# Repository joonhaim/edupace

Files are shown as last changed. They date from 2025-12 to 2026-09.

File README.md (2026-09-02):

<p align="center">
<p align="left">
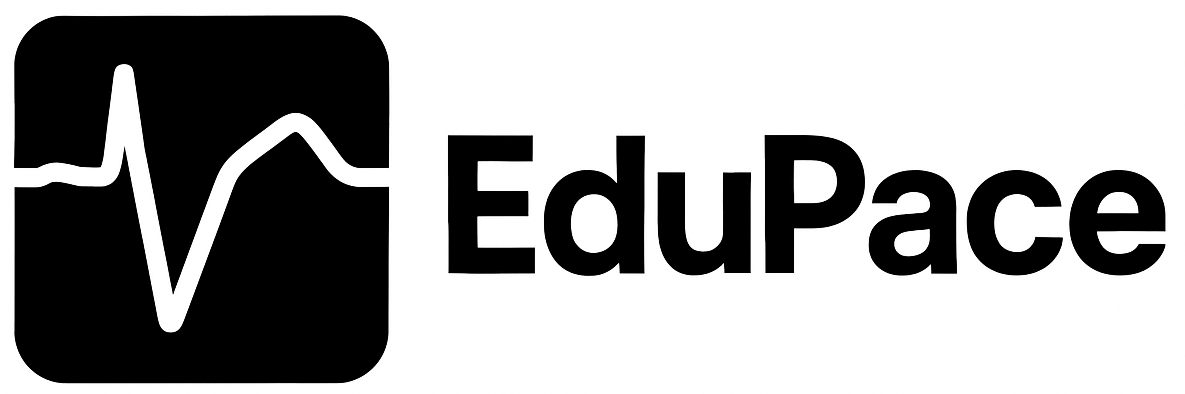
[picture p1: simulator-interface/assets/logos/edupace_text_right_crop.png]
EduPace
  
</p>
</p>

EduPace is an educational simulator that trains nurses and students to configure a temporary external single-chamber pacemaker. It provides realistic practice in pacing, sensing, and threshold adjustments by replicating the behaviour of the Medtronic 53401 Temporary External Pacemaker. The system combines a software-based ECG and pacing simulator with a physical control unit that includes knobs, LEDs, and a display, allowing users to interact with the device as they would in a clinical setting.

Developed within the TU Delft Minor Biomedical Engineering in collaboration with the Reinier de Graaf Hospital (Delft, Netherlands).

[**EduPace Project Report**](report.pdf) 

---

## Installation & Setup
[**EduPace User Manual**](simulator-interface/assets/pdf/EduPace_User_Manual_EN.pdf)

### **Web simulator**
[**Launch the EduPace simulator**](https://joonhaim.github.io/edupace/)

The hosted simulator runs in desktop Google Chrome or Microsoft Edge. Connecting the physical EduPace device requires granting USB serial access when prompted; virtual controls remain available without hardware. Session logs and optional operator names stay in the browser's local storage and are not uploaded.

### **Requirements**
- Arduino GIGA R1 WiFi
- Arduino GIGA Display Shield
- Google Chrome / Edge (WebSerial support)
- USB-C cable

### **Setup**
1. Clone this repository  
2. Upload `hardware/EduPace2025.ino` to the GIGA  
3. Open the EduPace UI in your browser or download the installer from Releases.
4. Connect the EduPace device to the computer with a USB cable.  
5. Begin a training scenario

---
## Repository Structure

```text
.
├── .github/                  # GitHub workflows and configuration
├── README.md
├── package.json               # Electron wrapper metadata and scripts
├── package-lock.json
├── cad/                       # Mechanical CAD design files and exports
├── arduino/                   # Firmware and hardware assets
│   ├── README.md
│   ├── digital.c
│   └── EduPace_final/         # LVGL UI, serial logic, and encoder handling
│       ├── *.ino
│       ├── key.c
│       ├── lv_conf.h
│       ├── edupace_logo*.{c,png}
│       └── tu_logo.{c,jpg}
├── electron/                  # Electron wrapper for the simulator
│   ├── about.html
│   ├── icons/
│   ├── main.js
│   └── preload.js
└── simulator-interface/       # ECG simulator & WebApp Interface
    ├── assets/
    ├── data/
    ├── ecg/
    ├── js/
    ├── styles/
    └── index.html
```

___

## Contributors

**Minor BME 2025 Team:** 
Ashley Jacobi, Süheyla Nurlu, Cees Vlasman, Adrien Joon-Ha Im

**Clinical Supervisor:** 
Paul Verschuren, Reinier de Graaf Hospital

---

### Contributions

**Ashley Jacobi**
- Researched physiological ECG morphology and clinical requirements
- Designed ECG generation engine (real-time Bézier-based cycles)
- Developed pacemaker timing system (sensing, inhibition, capture logic)
- Led documentation work and coordinated communication with the hospital and clinical supervisors

**Süheyla Nurlu**
- Implemented Arduino-side functionality (encoders, knobs, buttons, LEDs)
- Developed hardware interaction logic and Serial communication routines
- Managed wiring, pin mapping, and microcontroller integration

**Cees Vlasman**
- Designed enclosure components and mechanical layout (CAD modeling)
- Executed 3D printing, hardware assembly, and fit verification
- Ensured ergonomic alignment of knobs, display, and casing
  
**Adrien Joon-Ha Im**
- Designed and implemented the UI/UX flow, layout system, and visual interface
- Integrated UI components: pacing/sensing indicators, alarms, waveform rendering
- Built WebSerial communication protocol between Arduino and simulator
- Implemented PVC/PAC logic, QRS width modulation, and threshold drift
- Structured the scenario engine and front-end simulator architecture

---
## Limitations & Future Work

- Dual-chamber pacing implementation
- Improvement of morphology
- Expand number of clinical cases

---
## AI Assistance

Generative AI tools, including Codex, were used for selected non-critical development tasks. All important design choices, simulator behaviour, and final validation remained the responsibility of the project team.

---
## Disclaimer

EduPace is **for educational use only** and **not a medical device**.

---

## License
MIT License

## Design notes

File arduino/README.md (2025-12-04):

# EduPace Hardware 

## Hardware Requirements 
 - Arduino Giga R1
 - Giga Display Shield (480×800)
 - 3 Incremental Rotary Encoders (for Pace, Output, and Sense)

## Software Requirements

- Arduino IDE 
- LVGL graphics library (9.4.0)
- Arduino_H7_Video library
- Arduino_GigaDisplayTouch library
- Download digital.c file and add it inside the font folder of Arduino "C:\..\..\..\Arduino\libraries\lvgl\src\font\digital.c"

## Features

- Touch-enabled lock button
- Touch-enabled power button
- Real-time display of Pace, Output, and Sense parameters
- Rotary encoder input for adjusting values
- LED indicators for status feedback
- Serial communication for external monitoring/control
- Graphical dials and digital readouts for parameter visualization
- Flickering LED effect to simulate device activity

## Serial Communication
- Setial Baud rate: 115200
### Communication Format
► Incoming Serial Commands:
- GREEN_ON
- GREEN_OFF
- BLUE_ON
- BLUE_OFF
  
► Outgoing Serial Messages:
- PACE=< value >, OUTPUT=< value >, SENSE=< value >
- POWER_ON
- POWER_OFF

### User Interaction
► Power Button:
   - Hold > 2 seconds  → Toggle ON → OFF
   - Single press      → Toggle OFF → ON
   - ignored when locked
     
► Key Button:
- Single press  → Lock / Unlock
- If no value (pace, output, sense) has changed for more than 60 seconds, the system automatically locks.
  
► Encoder Knobs:
- Rotate to adjust PACE, OUTPUT, or SENSE
- Rotation ignored when locked
   
## Pin Connections
| Component | Signal | Arduino Pin | Notes |
|---|---|---|---|
| ENCODER 1 | CLK (A) | 2 | Pace rotary encoder |
| ENCODER 1 | DT (B)  | 3 | Pace rotary encoder |
| ENCODER 2 | CLK (A) | 6 | Output rotary encoder |
| ENCODER 2 | DT (B)  | 7 | Output rotary encoder |
| ENCODER 3 | CLK (A) | 12 | Sense rotary encoder  |
| ENCODER 3 | DT (B)  | 13 | Sense rotary encoder  |
| Power | +5V | +5V | Supply voltage |
| Ground | GND | GND | Common ground |

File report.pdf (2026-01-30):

EduPace: A Simulator for Temporary External Pacemaker Training

# EduPace: A Simulator for Temporary External Pacemaker Training

Süheyla Nurlu (5978637), Adrien Joon-Ha Im (4999924), Cees Vlasman (5708273), Ashley Jacobi (5973503)

E-mail: snurlu@tudelft.nl, aim@tudelft.nl, cvlasman@tudelft.nl, ajacobi@tudelft.nl
Abstract

Temporary external pacemakers are used to stabilise patients with acute bradycardia and atrioventricular conduction disorders. Because these devices are rarely used in daily clinical practice, nurses have limited opportunity to develop confidence in their operation. EduPace was developed as a training simulator based on the Medtronic 53401 single-chamber temporary external pacemaker. The system replicates the device’s appearance and controls using a microcontroller-based interface with rotary encoders and a graphical display, while a desktop application simulates electrocardiogram signals and pacemaker behaviour in real time. Feedback from nursing staff indicated that EduPace provides a realistic and intuitive hands-on training experience. EduPace offers an accessible tool for temporary external pacemaker education.

Keywords: Training tool, Medtronic 53401, Single-chamber external temporary pacemaker, Ventricular pacing

### 1. Introduction

A temporary external pacemaker is a device that stimulates
heart contractions to maintain a sufficient cardiac rhythm in patients suffering from various forms of cardiac arrhythmia [1]. Unlike permanent pacemakers, temporary pacemakers are not surgically implanted and are used to transiently stabilise a patient’s cardiac rhythm. They are often used during surgical procedures, or while awaiting implantation of a permanent pacemaker, to manage slow heart rhythms (bradycardia), caused by sinoatrial (SA) node dysfunction or various levels of atrioventricular (AV) blocks [2].

Temporary external pacemakers contain a pulse generator that produces an electrical signal to stimulate heart contraction. This pulse generator is connected to the heart via heart leads. In single-chamber pacemakers, leads are placed in either the right atrium or ventricle, while in double-chamber pacemakers, leads are placed in both chambers. Ventricular pacing is of particular significance in treating bradycardia caused by AV blocks, as these conditions hinder or prevent electrical conduction between the atria and ventricles. The degree of an AV block can be classified as either first, second, or third degree, with a higher degree indicating greater severity. A first-degree AV block is characterised by slow conduction between the atria and ventricles, represented by a long PR interval on an electrocardiogram (ECG) [3]. Second-degree AV blocks result in occasional loss of conduction. This appears on an ECG as a P wave not followed by a QRS complex [4]. In third-degree, or complete AV blocks, there is no conduction between the atria and ventricles, resulting in uncoordinated P waves and QRS complexes. While the intervals between adjacent P waves and adjacent R wavesremain constant, the PR interval varies, and P waves occur more frequently than R waves. Thus, this condition is characterised by a lower ventricular rate than atrial rate [5]. Left untreated, AV blocks can cause fainting, shortness of breath and reduced blood flow to the rest of the body [6].

Medtronic is a key player in the market for single-chamber temporary pacemakers, with models such as the 53401, as pictured in Figure 1, popular in hospitals worldwide [7].

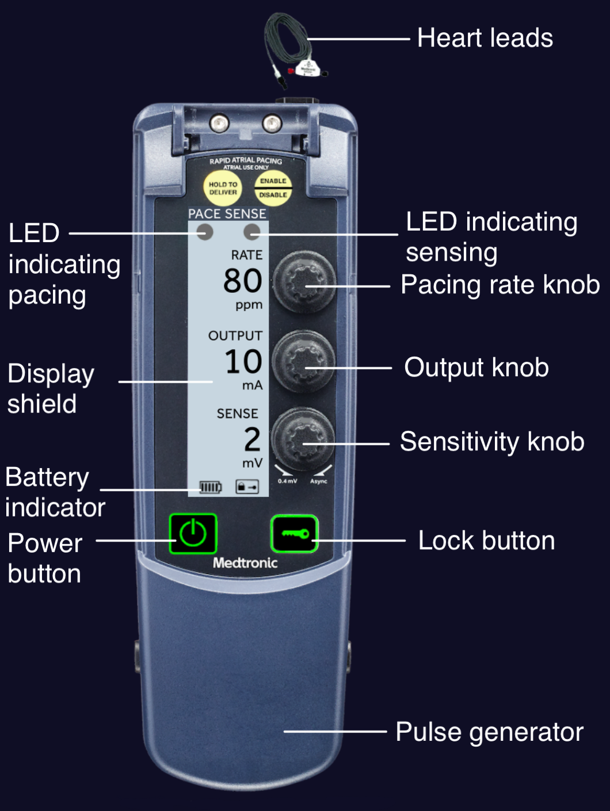
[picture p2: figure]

Figure 1: Components of Single Chamber Temporary External Pacemaker (Medtronic 53401) [8]

The pacemaker senses the patient’s intrinsic heart rhythm and paces according to the rate, output and sensitivity settings, which can be controlled using knobs on the device.

### 1.1 Problem Statement

At the Reinier de Graaf hospital, temporary external pacemakers are rarely used in the Cardiac Care Unit. Accordingly, nurses have limited opportunity to maintain routine proficiency and lack confidence in using them during emergency situations. Existing solutions to this problem include Medtronic’s VirtualEPG [8] simulation, but as this tool does not provide hands-on experience with using the device, it does not fully resolve the issue. Accordingly, the EduPace aims to address the shortcomings of the Medtronic VirtualEPG, to provide nurses with confidence in using temporary external pacemakers.

### 1.2 Project goal

The goal of this project is to develop an educational training tool that helps nurses gain practical experience and confidence in using a single-chamber temporary pacemaker for ventricular pacing. This project builds on a previous student project that successfully took the first steps toward creating a training tool for external pacing.
In the previous project, a physical training device was developed using an Arduino Mega microcontroller connected to a laptop running an ECG simulation. The system responded in real time to changes in the pacemaker settings, allowing users to see the effects of their adjustments. The final prototype of this project served as an important inspiration for the current work.
Based on feedback from hospital staff, several aspects were identified for further improvement. These include the choice of microcontroller and display shield, the overall ease of use, the realism of the simulation, and the ergonomics and appearance of the device. The aim of this project is to improve the initial design by addressing these points and by actively incorporating feedback from nurses and clinical staff throughout the development process. In this way, the final training tool is intended to better match real clinical practice and user needs.

### 2. Materials and Design

The material selection and overall design of EduPace were carefully considered to provide clinicians with an experience that closely resembles the Medtronic 53401. To achieve this, the design approach was divided in three main aspects.

The first aspect is hardware design, which focusses on the physical electronic components, including rotary encoders, the interactive display and their integration and interaction within the system. The second aspect is software design, which involves simulating ECG patterns of an imaginary patient across various clinical scenarios to support realistic training and evaluation. The third aspect is the physical device design which addresses the casing of the electronic components with emphasis on ergonomics, simplicity and ease of use.

While the hardware and physical device aim to replicate the functionality, appearance and user interaction of the Medtronic 53401 as closely as possible, the software design focusses on realistically simulating the effects of an external pacemaker on a patient.

### 2.1 Hardware Design

The hardware of EduPace is designed around the Arduino Giga R1 microcontroller along with its compatible display shield. Three incremental digital rotary encoders are integrated to adjust the rate, output and sensitivity parameters.

### 2.1.1 Microcontroller

A microcontroller is a computer on a single chip. It includes a processor (CPU), memory (RAM/ROM) and input/output (I/O) peripherals designed to perform specific tasks. Arduino is one of the most widely used microcontroller platforms which comes with its own integrated software (IDE). One of the main advantages of Arduino is its simplified programming language based on C/C++ along with a large collection of libraries, as it is an open-source platform. Further, Arduino supports a wide range of electronic components such as display shields.

Among the different Arduino boards available, the Arduino Giga R1 has been selected instead of the Arduino Mega, which was used in the previous version of EduPace. The primary reason for this choice is that the Arduino Giga R1 display shield is only compatible with the Arduino Giga R1 board. Furthermore, the display unit requires a more powerful microcontroller to run graphical libraries efficiently and provide a smooth user interface. The Arduino Giga R1 meets these requirements, as it is significantly more powerful than the Arduino Mega.

### 2.1.2 Display Shield

The display is a crucial component of EduPace, as it enables effective interaction between the device and the user. In the previous EduPace design, no graphical display was included and instead, three 7-segment displays were used to indicate current parameter values as shown in Appendix 1, Figure 1.3. However, the Medtronic 53401 includes a full display screen that shows not only the parameter values, but also labels, units, lock/unlock status of the device and LEDs for pacing and sensing activities.

To better align EduPace with the Medtronic 53401, the transition from 7-segment displays to an Arduino Giga display shield was considered an appropriate design choice, as it improves user interaction and provides greater freedom in design. The Arduino Giga display shield features an 800x480 RGB touchscreen and supports the LVGL framework, an open-source graphics library for creating user interfaces on a wide range of microcontroller and processors. Thus, the ability to use LVGL represents a significant advantage of development using Arduino.

### 2.1.3 Rotary Encoders

The Medtronic 53401 has three rotation knobs to adjust rate, output and sensitivity values. The knobs are incremental and provide a slight click at each step. Based on these design constraints, digital incremental rotary encoders were selected, as they closely resemble the behaviour and user experience of the Medtronic controls.

Each rotary encoder is powered by a 5V supply provided by the Arduino, with a common ground connection. The encoder's CLK (clock) and DT (data) pins are connected to the Arduino's digital input pins. As the knob is rotated, these two pins generate square-wave signals that are phase shifted by 90°. An algorithm created on the Arduino continuously compares the states of the CLK and DT signals to determine the direction of rotation. A difference between the DT and CLK states indicates clockwise rotation while matching states indicate counterclockwise rotation.

### 2.1.4 Layout and Graphics

When designing the layout and graphics of EduPace, similarity in design to the Medtronic 53401 and user friendliness were key considerations. EduPace starts with a splash screen (Appendix 2), so the user can click on START when they are ready to practice. Once activated, the main interface is displayed.

As shown in Figure 2, the main screen displays three indicators: Rate, Output and Sense. Each of these parameters is also represented numerically and visually through corresponding dials. At the top left and right of the screen, there are two LEDs displayed to indicate pacing and sensing. At the bottom left of the screen, there is a touchable power button, and on the bottom right, there is a Lock/Unlock button. Additionally, there is also a symbolic battery icon to make it more realistic.

Together, these elements reflect all visual features of the Medtronic 53401 while keeping the interface realistic and easier to use. Although the dials are not present on the Medtronic 53401, they are found on model 5392. They were intentionally added to improve clarity and usability.

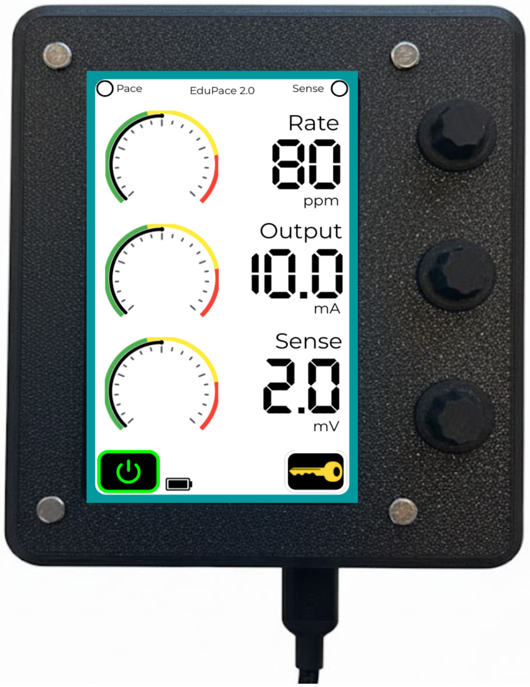
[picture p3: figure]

Figure 2: EduPace main user interface

### 2.1.5 Device Functionalities

As shown in Appendix 2, similar to the reference device, EduPace has numerous user interfaces depending on the device state. Although the EduPace device is already powered when connected to the computer, the user is still required to press and hold the power button to begin transmitting signals. To create the impression that the device is powered off, the background colour is dark grey and numerical values are replaced by two dashes. When activated, the power button turns green, default numerical values appear and the background changes to white to indicate active operation. Like Medtronic 53401, to power off the device, the power button should be pressed for more than 2 seconds, and the device must not be in the lock state.

Another key feature is the Lock/Unlock function. On the Medtronic device, locking prevents accidental changes to parameter values and the system automatically locks after 60 seconds of inactivity. EduPace follows the same principle. When the user presses the lock button, the border colour of the button turns yellow, and the background turns soft teal. Any rotation of the knobs does not affect the parameter values while locked.

Although the model 53401 has two physical LED indicators, these are simulated on the EduPace display, instead of using physical components. The left LED flashes green during pacing events, while the right LED flashes blue during sensing events. These indicators operate based on commands received from the computer.

### 2.2 Software Design and Architecture

To simulate the behaviour of the external temporary pacemaker, a desktop application was developed. The user can connect the EduPace device to the computer and launch the EduPace application following the instructions in the user manual (Appendix 11).

### 2.2.1 EduPace Desktop Application

As seen in Appendix 3, the EduPace desktop application has four main pages. The first one is the main dashboard, where the user can select the training scenario, see recent practice attempts, and track their progress. The training tab is the main page that allows the user to practice setting the correct parameters to the temporary external pacemaker. It renders the ECG waveform and responds to the rate, output, and sensitivity parameters of the connected device. After each session, the user is given feedback on whether they were successful in stabilising the patient, and how much time it took them to do so. A session log tab is also present for the user to view their previous sessions, and finally, an instructions page for quick troubleshooting.

To improve the user experience in comparison to the first iteration of EduPace, which ran as a standalone executable, the system was redesigned as a cross-platform web application using HTML, CSS, and JavaScript. This web application was then packaged as an Electron desktop app to ensure compatibility with both Windows and macOS.

The EduPace software was designed using a modular architecture to allow for future expansion. Core components such as ECG waveform generation, clinical scenario logic, and device communication were separated into independent modules. This approach allows new clinical scenarios, pacing modes, or more physiologically detailed ECG models to be added without requiring major changes to the existing system. The full EduPace application is available via a public GitHub repository (Appendix 3).

### 2.2.2 Communication Protocol

The Arduino works in conjunction with a connected computer running the EduPace software. A physical connection is made using a USB-C cable and all data exchange occurs through serial communication. The serial communication is configured to a baud rate of 115200 bits per second on both the Arduino and the computer. This rate is selected to ensure the balance between transmission speed and the communication stability. The system overview is shown in Appendix 4.

When the user adjusts the rotary encoders, the Arduino sends the updated values for rate, output and sensitivity to the computer. Furthermore, the Arduino sends a power status message whenever the device is turned on or off. These messages are received by the computer and processed by the EduPace software in real time.

The Arduino also receives control signals sent from the computer. There are four kinds of control signals that the system supports: GREEN_ON, GREEN_OFF, BLUE_ON and BLUE_OFF. When one of these signals is received, the Arduino processes the command and updates the corresponding pacing and sensing indicator LEDs on the display accordingly.

On the software side, the serial communication is handled using the WebSerial API. This allows the EduPace interface to establish connection with the Arduino without requiring additional native drivers. Compared to the previous EduPace interface, this design improves the connection stability and makes device setup simple by making it plug-and-play.

### 2.2.3 Modelling ECG Traces

ECG traces were generated using the Rational Bézier-Bernstein model coded in Python, to simulate clinically realistic cardiac patterns. This approach was inspired by a paper from Chutchavong et al. and the previous EduPace project [9]. As seen in Appendix 5, the Rational Bézier-Bernstein model takes a collection of weighted points and interpolates between these to generate a smooth trace, with additional points improving the accuracy of the interpolation. The previous EduPace project used minimal points to model ECG traces. Accordingly, to improve accuracy, it was decided to obtain additional points through importing ECG traces into the software Desmos and plotting points along the trace. As seen in Appendix 6A-E this resulted in realistic models of normal sinus rhythm, ventricular pacing and various heart conditions.

### 2.2.4 Pacemaker Logic

The functioning of pacemakers is dictated by the sensitivity, rate and output settings. Pacemakers sense a patient’s intrinsic cardiac rhythm based on sensitivity. Sensitivity describes the voltage threshold above which signals can be detected. Thus, a lower value indicates that more signals will be detected, and the pacemaker is said to have a high sensitivity. If the signal detected by the pacemaker falls below the set rate, the pacemaker will decide to pace. Pacemakers have an additional setting referred to as “Async”, where sensing does not occur and the pacemaker paces at the set rate, regardless of the patient’s intrinsic cardiac rhythm. Pacing will result in cardiac depolarisation and thus, a heartbeat, if the output current is sufficient. The output threshold above which pacing results in cardiac depolarisation is referred to as the capture threshold.

To understand how to model the behaviour of the pacemaker, a decision tree was created, as seen in Appendix
7. This logic was then transferred to functions in Python that generate an ECG waveform that illustrates how the pacemaker responds to the input simulated patient heart rhythm and pacemaker settings.

### 2.3 Physical Device Design

The physical device is designed by focusing on the casing, with particular attention to ergonomics, simplicity, and ease of use. The goal was to create a device that closely resembles the look and feel of the original Medtronic 53401, making it familiar to clinicians and easy to use in practice.

Special attention was given to the dimensions, material, and shape of the device. To enhance usability, the casing was designed to be as thin and lightweight as possible, while still providing enough structural support. From an ergonomic perspective, the device was intended to be comfortable to hold and operate with one hand during training sessions. The final 3D CAD model can be seen below in Figure 3.

Figure 3: 3D CAD Model of EduPace Casing

### 3. Results

A survey (Appendix 8) was conducted and feedback from nurses was collected. The results (Appendix 9) indicate that EduPace is perceived as a valuable training device. Across respondents, participants indicated that repeated use would help them build or maintain confidence. EduPace received high ratings for ease of use, physical design, and overall usability, which support the suitability of the device as a training platform, especially for nurses that have limited prior exposure to external pacemakers.

However, some limitations were identified, primarily related to clinical realism and ECG behaviour for edge cases. Multiple respondents noted that certain rhythms such as second- and third-degree AV blocks were not always accurately represented. Additionally, issues related to pacing and sensing indicators during threshold adjustments were reported. These findings suggest that while EduPace performs well, further refinement of the ECG modelling and indicator logic is necessary to meet the expectations of more experienced users.

### 4. Discussion

This project builds on a previous student project that already included real-time ECG simulation and device interaction. This project focussed on three main changes. First, the hardware was updated to better resemble the controls and interface of the Medtronic 53401. Second, the ECG simulation software was adjusted to create more realistic pacing behaviour and clinical cases. Third, the device casing was redesigned to improve the ease of use. Feedback from nurses and clinical staff showed that these changes made the system easier to use and closer to clinical practice.

While the previous EduPace served as inspiration, the new iteration of the device had to be designed from scratch (see Appendix 1 for a comparison between the versions), which was very time consuming. Several challenges slowed down the development process. The 3D-printed casing had to be redesigned multiple times because early versions were too small or there were problems with the 3D printer. Rendering smooth ECG traces in real time was technically difficult, which is why the ECG display is not yet fully smooth. After feedback from clinical staff, the ECG logic had to be adjusted to better reflect pacing behaviour. A simplified ECG model was used, so some physiological signal features, such as signal superposition, are not yet included. Getting frequent feedback from hospital staff was difficult due to limited availability. The EduPace team consisted of engineering students only, which meant there was limited clinical knowledge within the team. This made it harder to fully understand the medical background of temporary pacing.

At this stage, EduPace only supports ventricular pacing modes. Atrial pacing and dual-chamber pacing are not yet included. Later versions could add these modes and include more clinical training cases. EduPace is a step towards a practical and user-focused training tool for temporary external pacemakers. With future additions in pacing modes, ECG realism, and training scenarios, the system can grow into a useful tool for pacemaker education.

Acknowledgements

We would like to thank our project supervisor Paul Verschuren and nurse Kim who have supported us through the development process. We would also like to extend our thanksto TU Delft for funding the development of this project (see Appendix 10 for associated costs).

References

[1] M. Crofoot, A. Sarwar, and A. J. Weir, “External pacemaker,” StatPearls - NCBI Bookshelf, Sep. 12, 2022.
[2] J. A. Puette, R. Malek, I. Ahmed, and M. B. Ellison, “Pacemaker insertion,” StatPearls - NCBI Bookshelf, Oct. 06, 2024.
[3] J. L. Buttner, “First degree heart block,” Life in the Fast Lane • LITFL, Jun. 11, 2024. https://litfl.com/first-degree-heart-block-ecg-library/
[4] E. B. Buttner, “AV Block: 2nd degree, Mobitz II (Hay block),” Life in the Fast Lane • LITFL, Oct. 31, 2025. https://litfl.com/av-block-2nd-degree-mobitz-ii-hay-block/
[5] J. L. Buttner, “AV block: 3rd degree (complete heart block),” Life in the Fast Lane • LITFL, Nov. 15, 2023. https://litfl.com/av-block-3rd-degree-complete-heart-block/
[6] “Heart block,” Cleveland Clinic, Oct. 14, 2025. https://my.clevelandclinic.org/health/diseases/17056-heart-block
[7] “Medtronic single-chamber temporary pacemaker.” https://www.medtronic.com/en-us/healthcare-professionals/products/cardiac-rhythm/pacing-systems/temporary-pacemakers/medtronic-single-chamber-temporary-pacemaker.htm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
[8] “VirtualEPG.”
https://epicardiowebgl.s3.amazonaws.com/mdt/epg/index.ht ml
[9] V. Chutchavong, K. Nualon, O. Sangaroon, and K. Janchitrapongvej, “A mathematical model for ECG waveform using rational Bezier curves and Bernstein polynomials,” IEEE, pp. 1–5, May 2014, doi: 10.1109/ecticon.2014.6839844.

# Appendix

Appendix 1: Medtronic 53401 vs EduPace

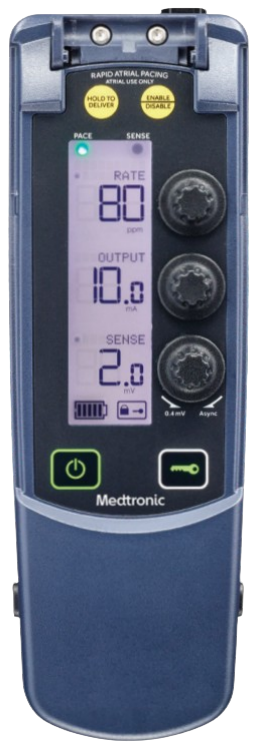
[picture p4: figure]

Figure 1.1: Medtronic 53401

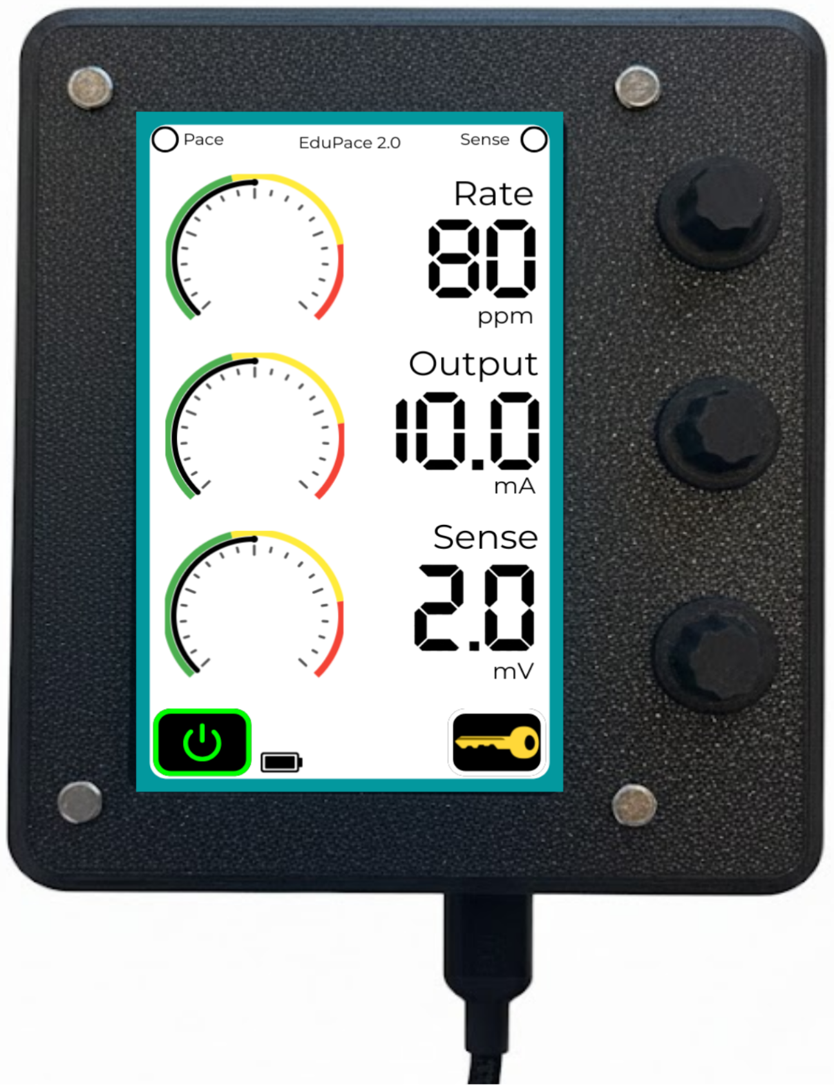
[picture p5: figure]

Figure 1.2: EduPace 2.0

Figure 1.3: EduPace 1.0

Feature | Medtronic 53401 | EduPace 1.0 | EduPace 2.0
Screen | Present | Not present | Present
Rate, output and sense indications and units | Present | Present in the form of text on stickers | Present
Rate, output and sense current values | Present | Present on 7-segment display | Present
Rate, output and sense values visual indicators | Not present, present on model 5392 | Not present | Present
Rate, output and sense rotary knobs | Present | Present, not similar to Medtronic | Present
Power button | Present | Not present | Present
Lock button | Present | Not present | Present
Pacing status indicator LED | Present | Present | Present on the display
Sensing status indicator LED | Present | Present | Present on the display
Lock indicator | Present | Not present | Not present, indicated by lock button colour change
Battery indicator | Present | Not present | Present but not functional
Asynchronous mode indication | "async" text shown, "--" instead of sense value | Present as LED | "async" text shown, "--" instead of sense value
RAP indicator LED | Present | Not present | Not present
Hand-held size | Present | Not achieved | Achieved
Protection cover | Present | Not present | Not present

Appendix 2: User Interface States

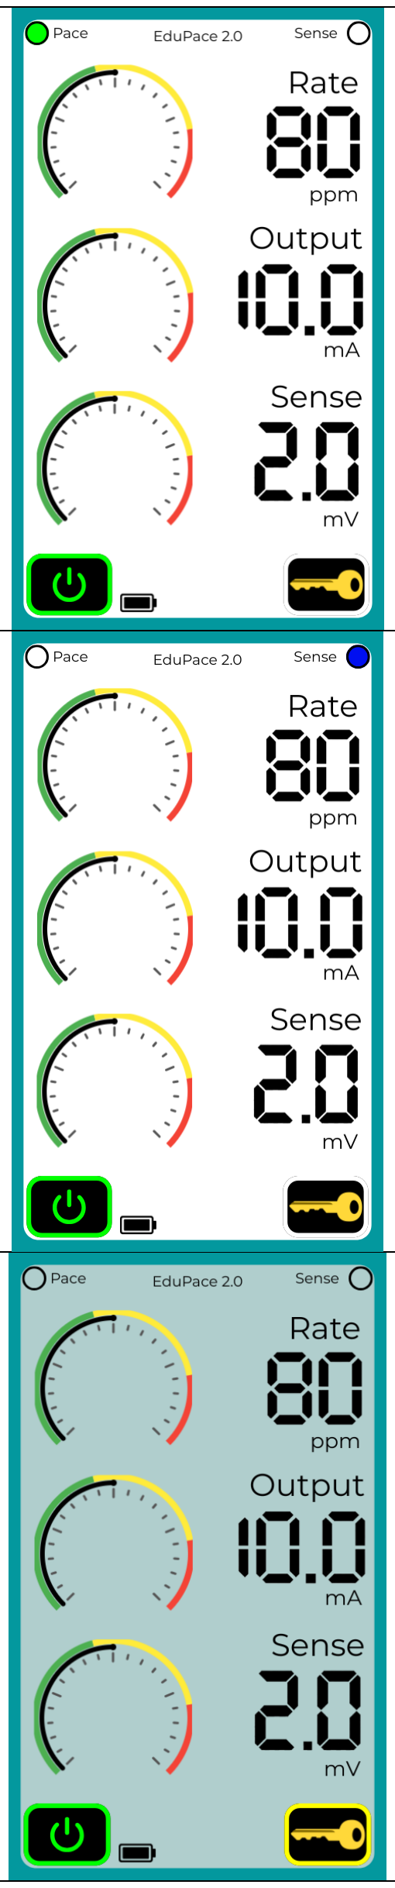
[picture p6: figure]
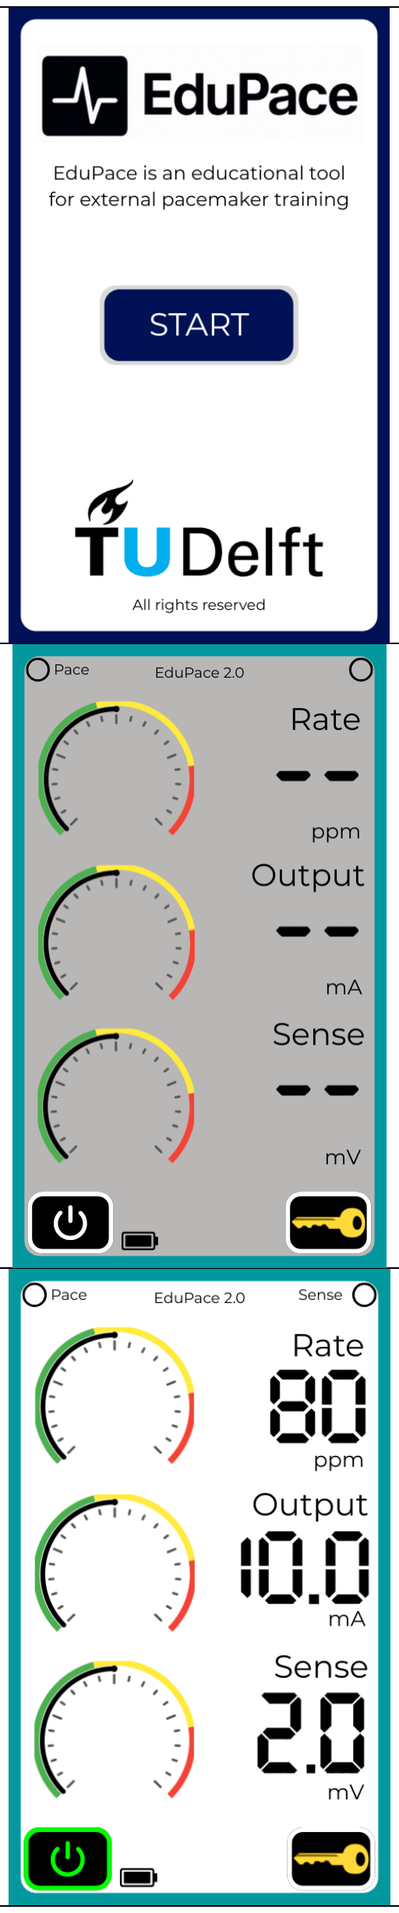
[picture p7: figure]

Splash screen Definition of EduPace and logos are shown

Power Off Background: dark grey Power button: inactive Lock button: inactive Dashes instead of numerical values

Power On Background: white Power button: active Lock button: inactive Variables start with default values

During Pacing Left LED at top is flashing green

During Sensing Right LED at top is flashing blue

System Locked Background: soft teal Lock button: active Variable values and dashes do not change

Appendix 3: EduPace App Interface

EduPace GitHub repository link: https://github.com/joonhaim/edupace A3.A Dashboard
The dashboard is the main landing screen and includes
navigation menus, a list of scenarios, progress tracking,
leaderboards, and recommendations for subsequent practice modules.

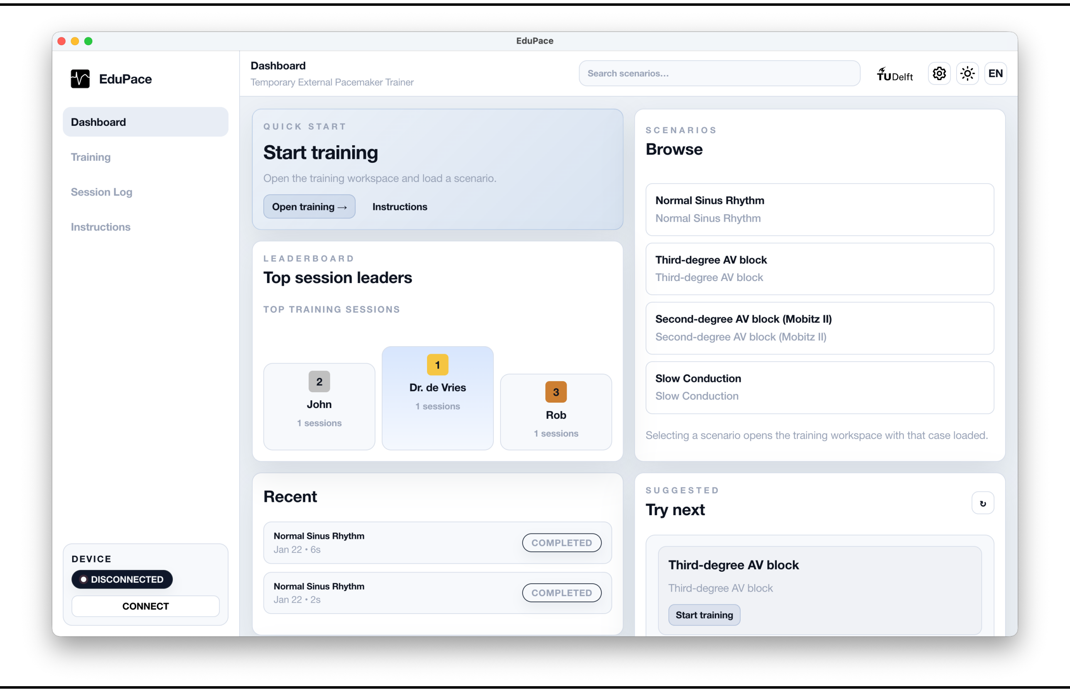
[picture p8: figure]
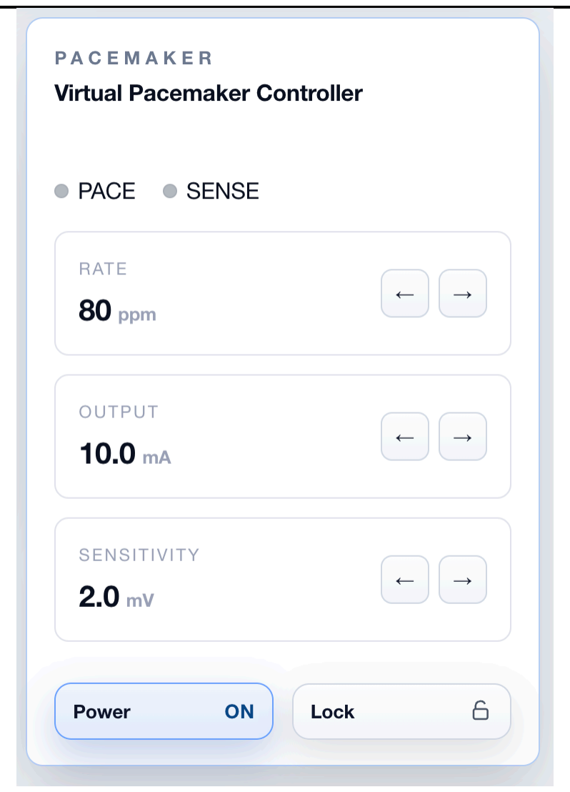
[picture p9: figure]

A3.B Training Tab
The Training tab is the main interface where ECG signals are simulated and users can adjust pacing parameters to practice appropriate pacemaker configuration.

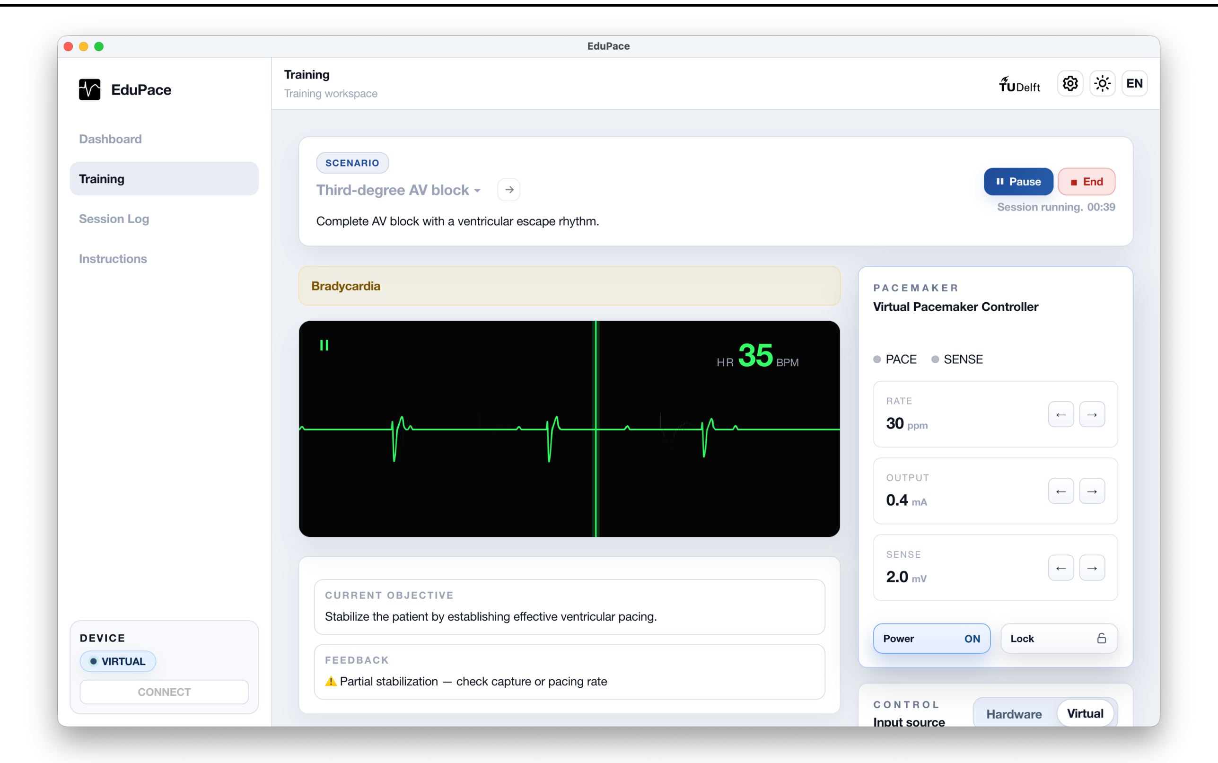
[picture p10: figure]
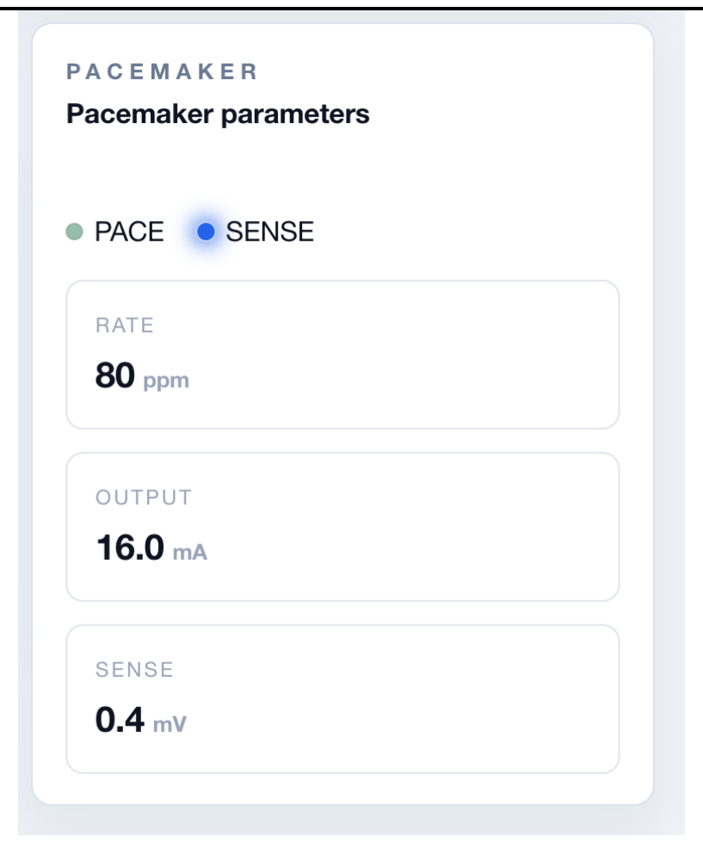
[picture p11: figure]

A3.C Session Review
After each session, a review is shown indicating whether the patient was successfully stabilized and the time required to achieve stabilization.

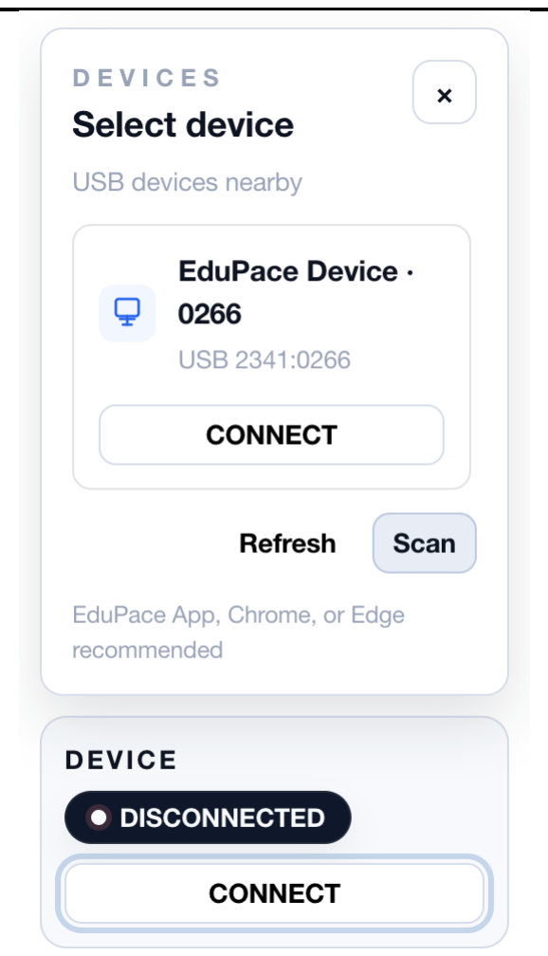
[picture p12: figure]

A3.D Connection
module

The connection module
allows users to connect
to a physical EduPace
device. Available
devices are listed and
pressing ‘CONNECT’
establishes
communication via
WebSerial.

A3.E Virtual Pacemaker The virtual pacemaker emulates the EduPace device when no hardware is connected. Pacing parameters, power and lock controls, as well as pace and sense indicators, remain fully functional.

A3.F Pacemaker Information The pacemaker information panel replicates the display of the physical EduPace device. When connected via USB, parameter values are updated using the physical control knobs.

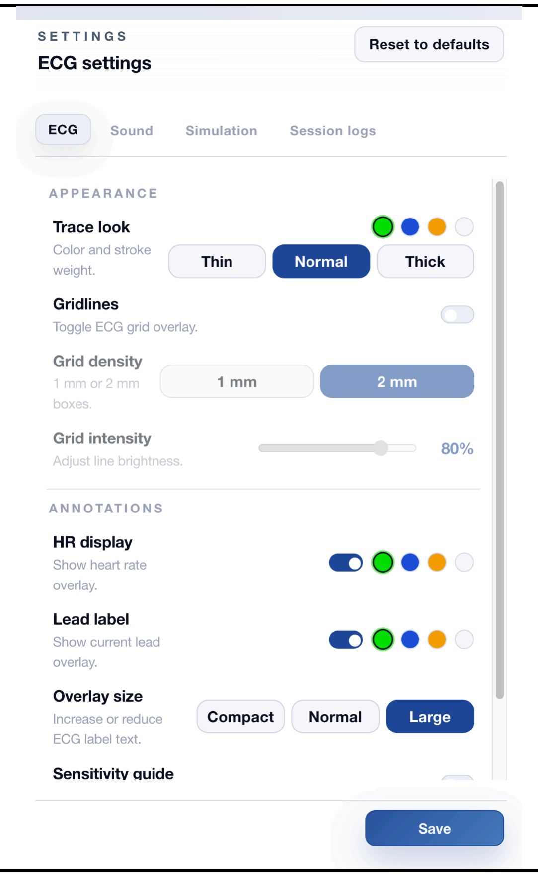
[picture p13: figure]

A3.G Settings pane The settings pane allows users to adjust application settings, including ECG appearance and overlays, as well as simulation parameters such as intrinsic heart rate.

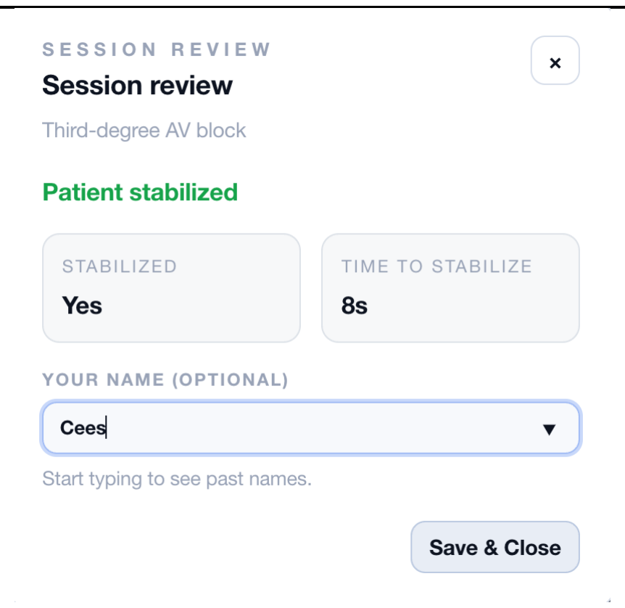
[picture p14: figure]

Appendix 4: System overview

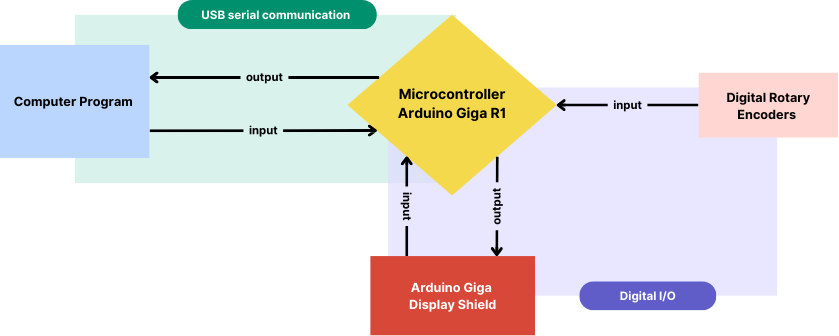
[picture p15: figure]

Appendix 5: Rational Bézier-Berstein Model

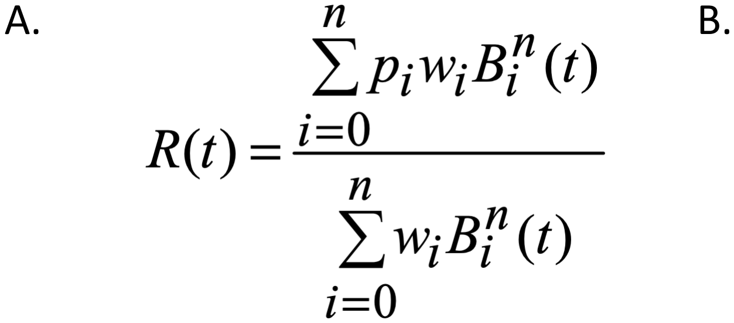
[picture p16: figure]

A5.A Trace R generated using Rational Bézier-Bernstein Model, where p is a point, w is a weighting factor and B is defined as in A5.B

Appendix 6: ECG traces

A

B

C

D

E

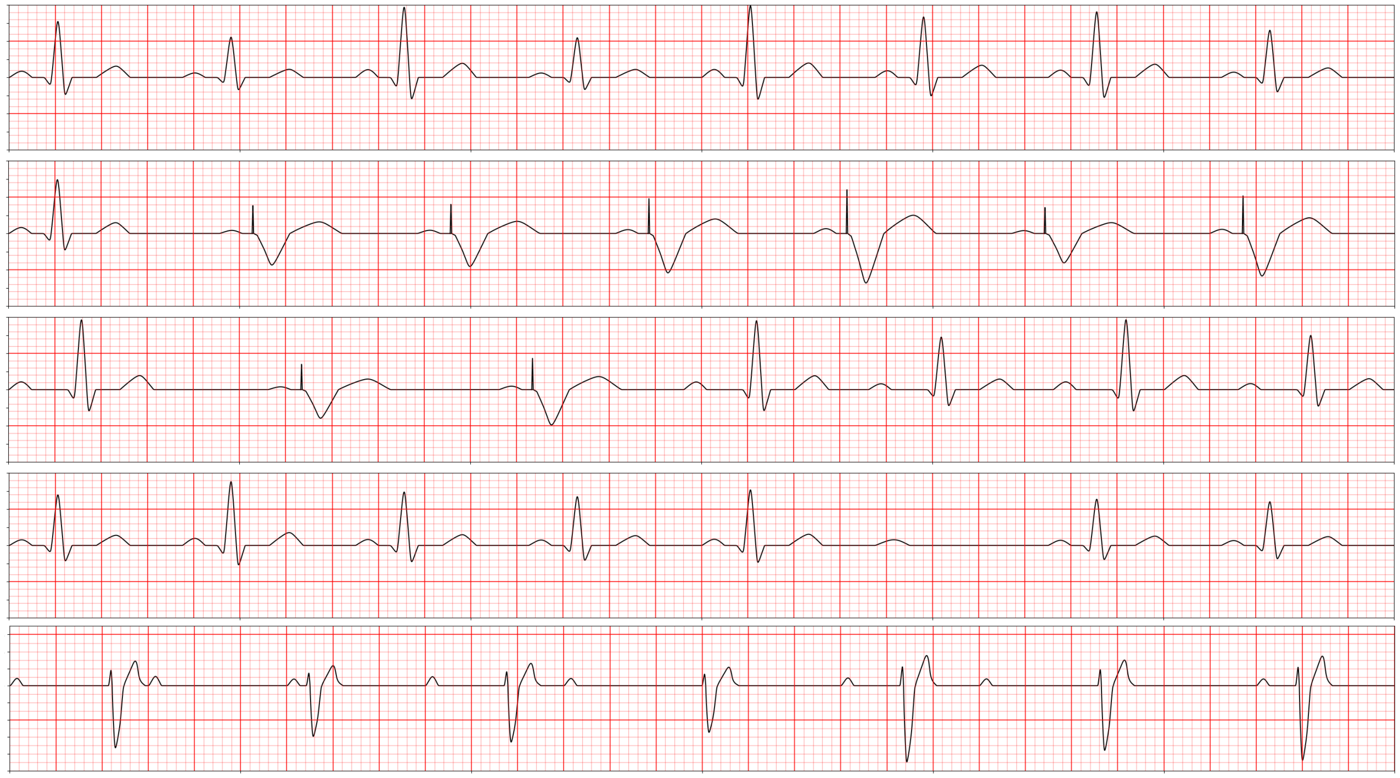
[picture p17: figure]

A6.A Normal ECG trace for patient heart rate of 80bpm A6.B Ventricular pacing for patient heart rate of 40bpm (bradycardia), pacemaker rate of 70ppm, sensitivity of 0.5mV and output of 1.7mA A6.C ECG trace for first degree heart block for patient heart rate of 75bpm, pacemaker rate of 60ppm, sensitivity of 0.7mV and output of 1.7mA A6.D ECG trace for second degree heart block for patient heart rate of 80bpm, pacemaker rate of 90ppm, sensitivity of 0.5mV and output of 1.3mA. Pacing doesn’t occur, as capture threshold isn’t reached A6.E ECG trace for third degree heart block for patient heart rate of 70bpm, pacemaker rate of 80ppm, sensitivity of 0.4mV and output of 1.3mA. Pacing doesn’t occur, as capture threshold isn’t reached

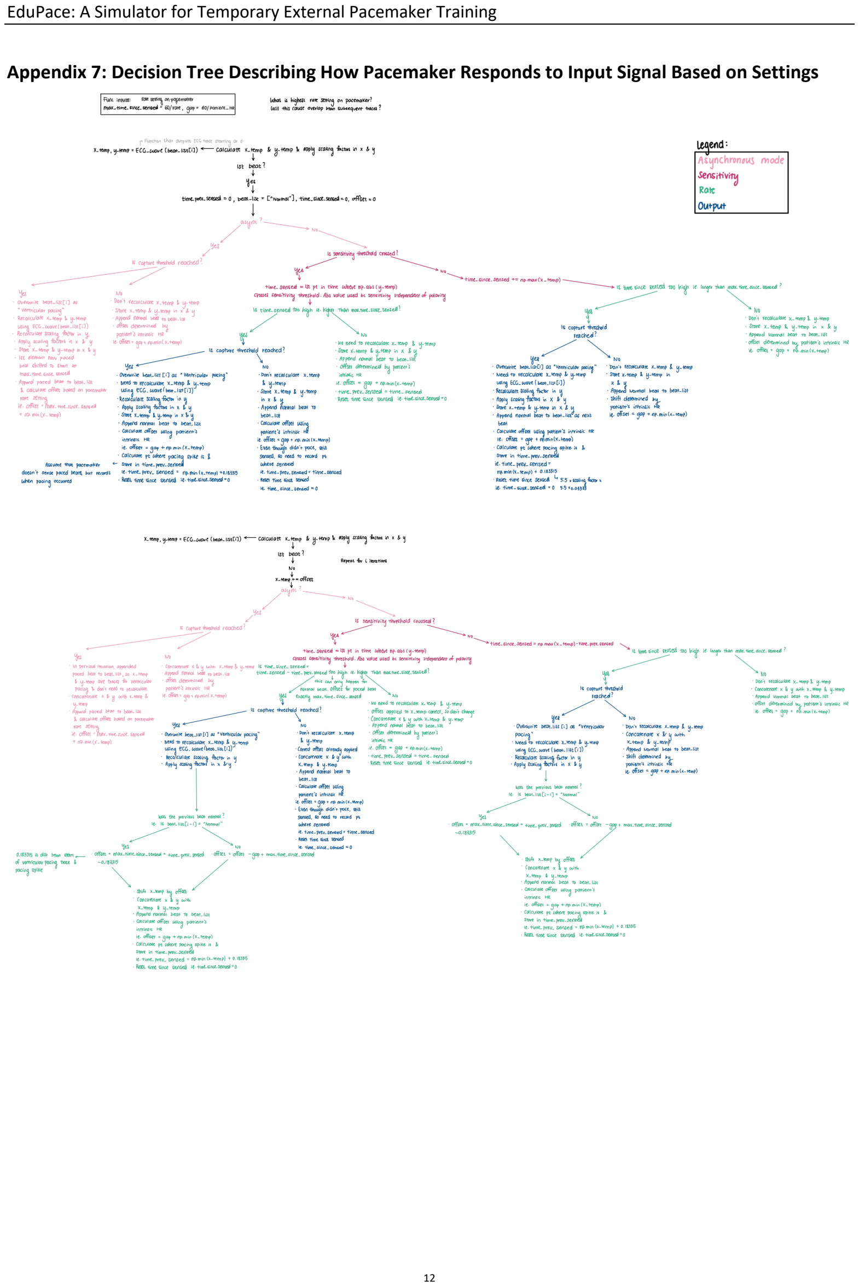
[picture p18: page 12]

Appendix 7: Decision Tree Describing How Pacemaker Responds to Input Signal Based on Settings

Appendix 8: Feedback Form

1- Role/Profession
2- Years of clinical experience
a. Less than 1 year
b. 1-3 years
c. 4-7 years
d. 8+ years

Before Using EduPace: Background
3- Have you previously used the Medtronic 53401 external pacemaker?
a. Yes
b. No
4- How long has it been since you last used the Medtronic 53401?
a. Less than 6 months
b. 6-12 months
c. More than 1 year
5- How often have you used the Medtronic 53401?
a. Rare
b. Occasionally
c. Frequently
d. Very frequently
6- Have you used any other external pacemaker?
a. Yes
b. No

Confidence & Expectations
7- How confident are you in using the Medtronic 53401 before using EduPace?
a. 1 to 10 (Not confident at all à Very confident)
8- Do you believe EduPace will help improve your pacing-related skills?
a. 1 to 5 (Not at all à Very much)
9- What specific skills would you like to practice?
a. Basic device setup
b. Understanding pacing modes
c. Adjusting output and sensitivity
d. ECG interpretation
e. Other

After Using EduPace – Self-Confidence & Learning 10- How confident do you feel after practicing with EduPace?
a. 1 to 10 (Not confident at all à Very confident)

11- Do you think practicing more often with EduPace would help build or maintain your confidence?
a. Yes
b. No
c. Unsure

12- To what extent did EduPace help you practice the skills you wanted?
a. 1 to 10 (Not at all à Completely

Product Experience
13- Did EduPace meet your expectations?
a. Not at all
b. Partially
c. Mostly
d. Completely
14- Which features did you find most useful?
a. EduPace device
b. EduPace software
c. Device layout and controls
d. Realistic ECG simulation
e. Pacing modes
f. User guide
15- How realistic did the training feel compared to a real external pacemaker?
a. 1 to 5 (Not realistic à Very realistic)
16- How easy was it to navigate on EduPace software?
a. 1 to 5 (Very difficult à Very easy)
17- How satisfied are you with the physical design and appearance of EduPace?
a. 1 to 5 (Very dissatisfied à Very satisfied) 18- How would you rate the overall ease of use of EduPace?
a. 1 to 5 (Very difficult à Very easy)
19- How clear was the user manual?
a. 1 to 5 (Not clear at all à Very clear)

Overall Feedback
20- What suggestions do you have for improving EduPace? Which aspects of EduPace do you think work well and should remain unchanged?
21- Would you recommend EduPace as a training tool to others?
a. Yes
b. No
c. Maybe
22- Anything else you would like to share about your experience with EduPace?

Appendix 9: Results From Feedback Form

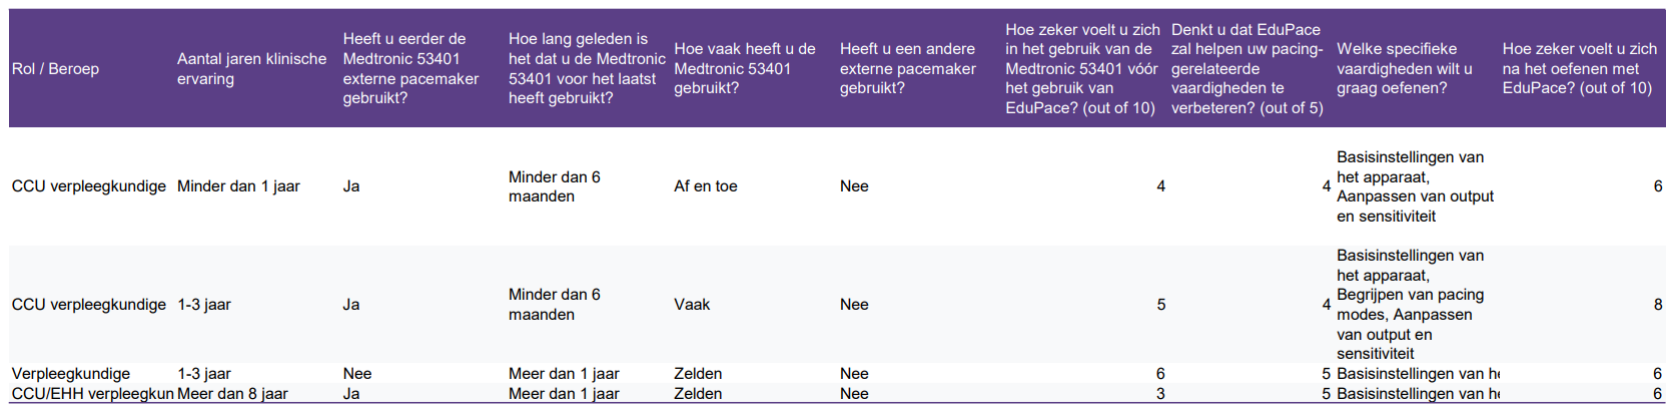
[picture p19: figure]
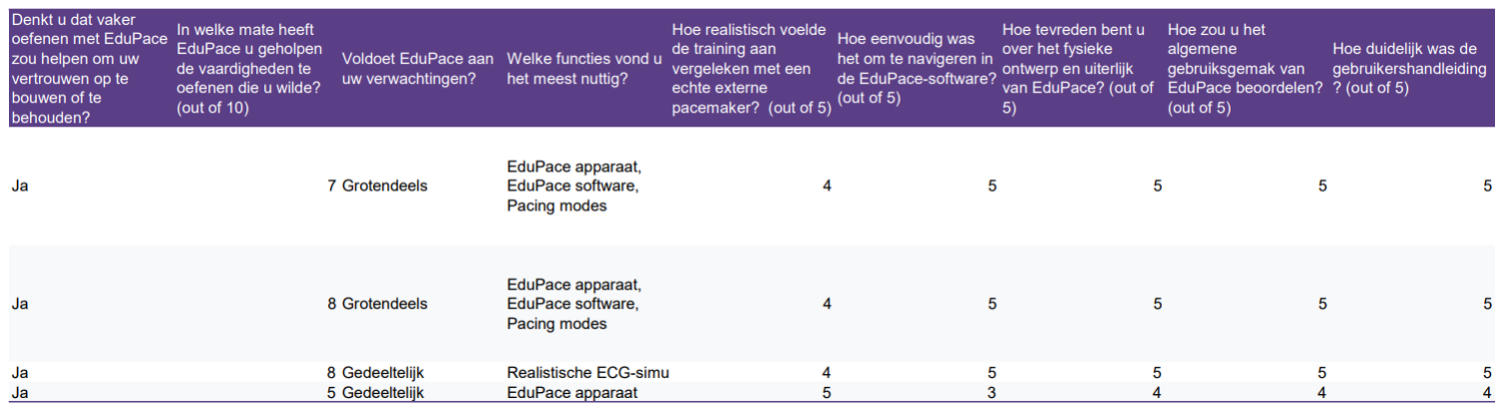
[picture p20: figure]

Appendix 10: Bill of Materials

| Qty | Unit Price (€) | Total (€)
Arduino Giga display bundle | 1 | 96.65 | 96.65
Rotary Encoders | 4 | 2.40 | 9.60
Jumper cables | 1 | 1.70 | 1.70
USB C to A cable | 1 | 2.49 | 2.49
Logo stickers | 1 | 2.25 | 2.25
Shipping cost | | | 4.99
Shipping cost | | | 6.87
Total | | | € 124.55

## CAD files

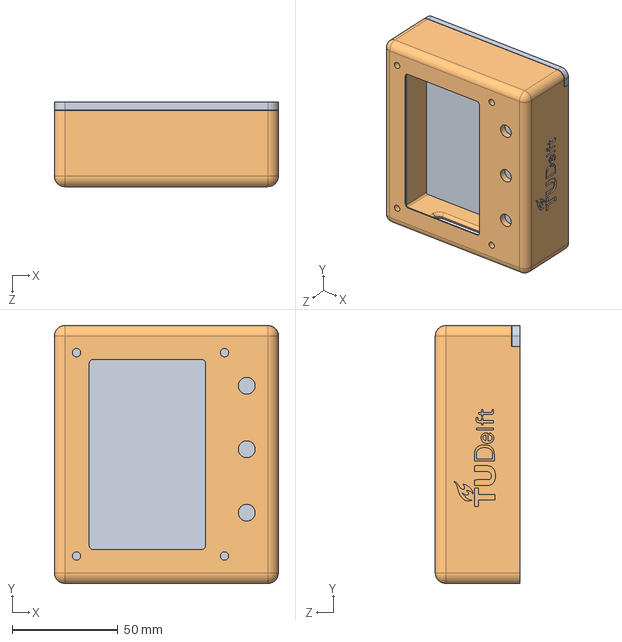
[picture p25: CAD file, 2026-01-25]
cad/Assembly EduPace.SLDASM
106.1 x 122.0 x 40.0 mm
Enclosure EduPace
Backside EduPace

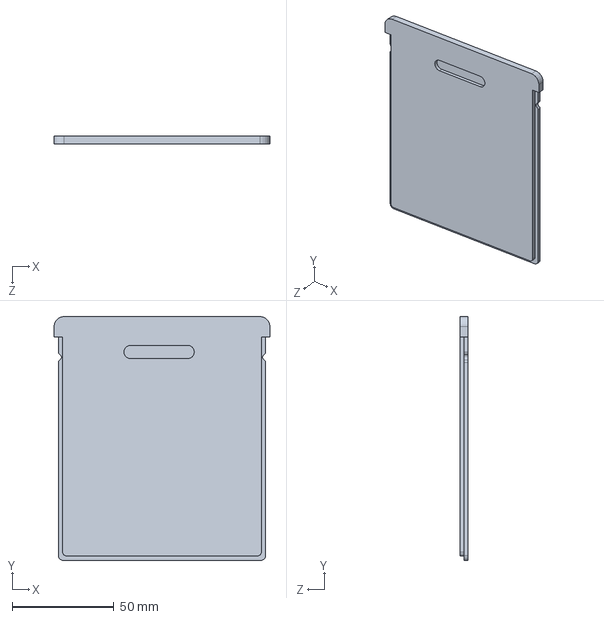
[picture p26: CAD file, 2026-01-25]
cad/Backside EduPace.SLDPRT
106.0 x 119.8 x 3.80 mm

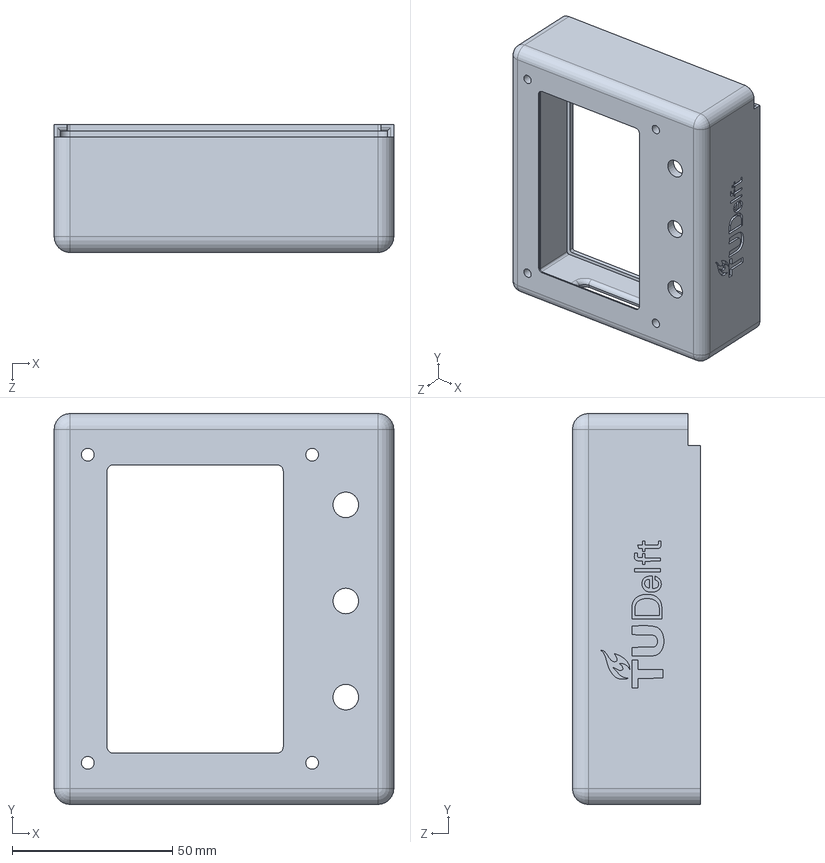
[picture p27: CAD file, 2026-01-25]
cad/Enclosure EduPace.SLDPRT
106.0 x 122.0 x 40.0 mm

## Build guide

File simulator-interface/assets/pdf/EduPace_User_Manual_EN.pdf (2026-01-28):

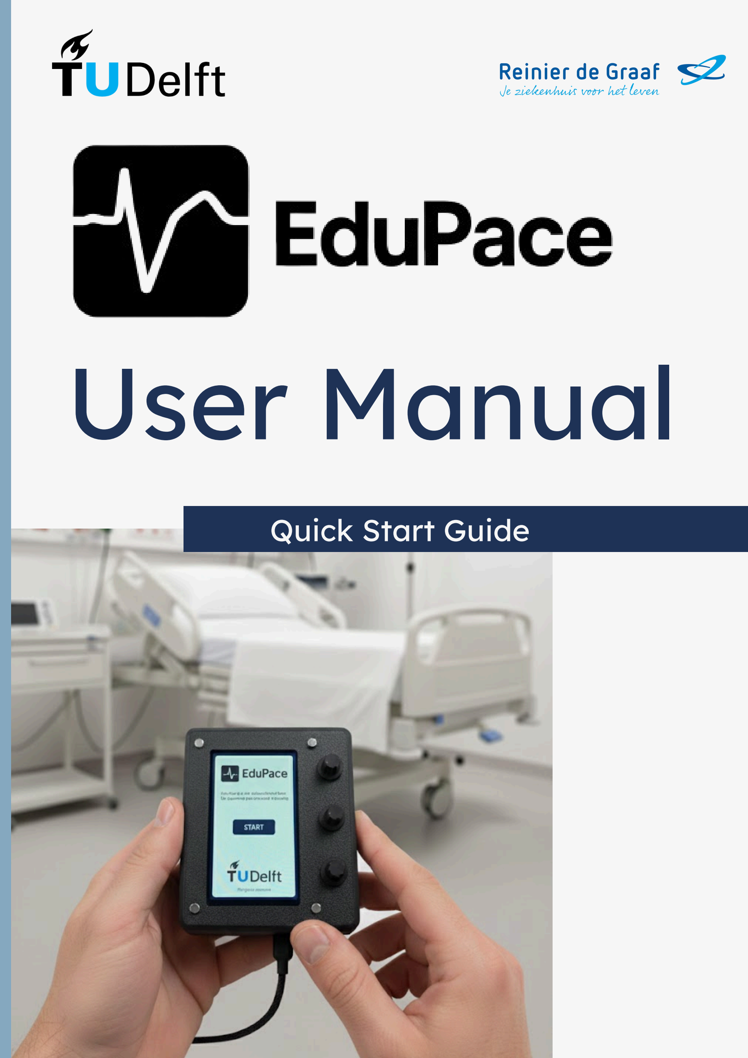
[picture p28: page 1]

# User Manual

## Quick Start Guide

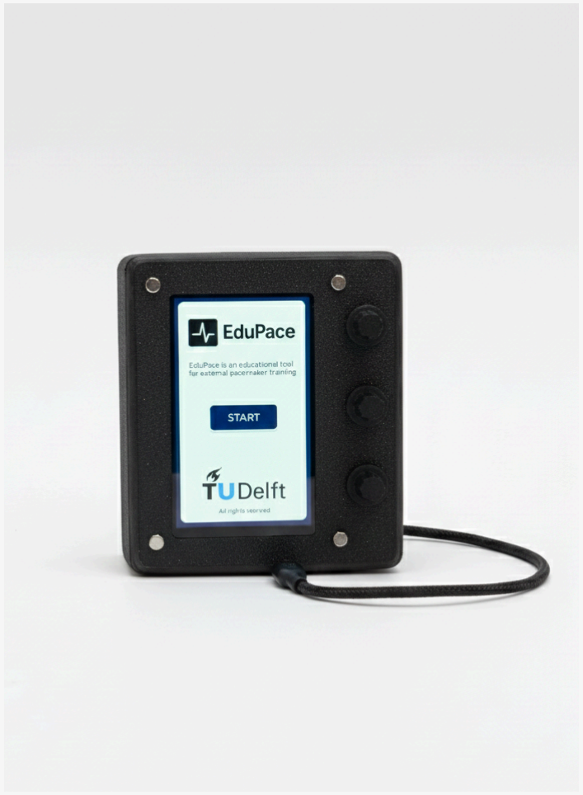
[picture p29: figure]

All rights reserved 2025

# What is EduPace?

EduPace is an educational training tool designed for practicing the use of an external pacemaker. It has been developed by university students from TU Delft for educational purposes, specifically to support the training of nurses and clinicians.

## Before you begin

# Reference Device

The design and functionality of EduPace are based on the Medtronic 53401 External Pacemaker, which was used as a reference during development.

# Disclaimer

EduPace is not a medical device and is not intended for clinical use. It is an educational exercise tool only and must not be used for diagnosis, treatment, or patient care. Always use certified medical devices in clinical settings.

## Controls and Indicators

8 | 9 | 10

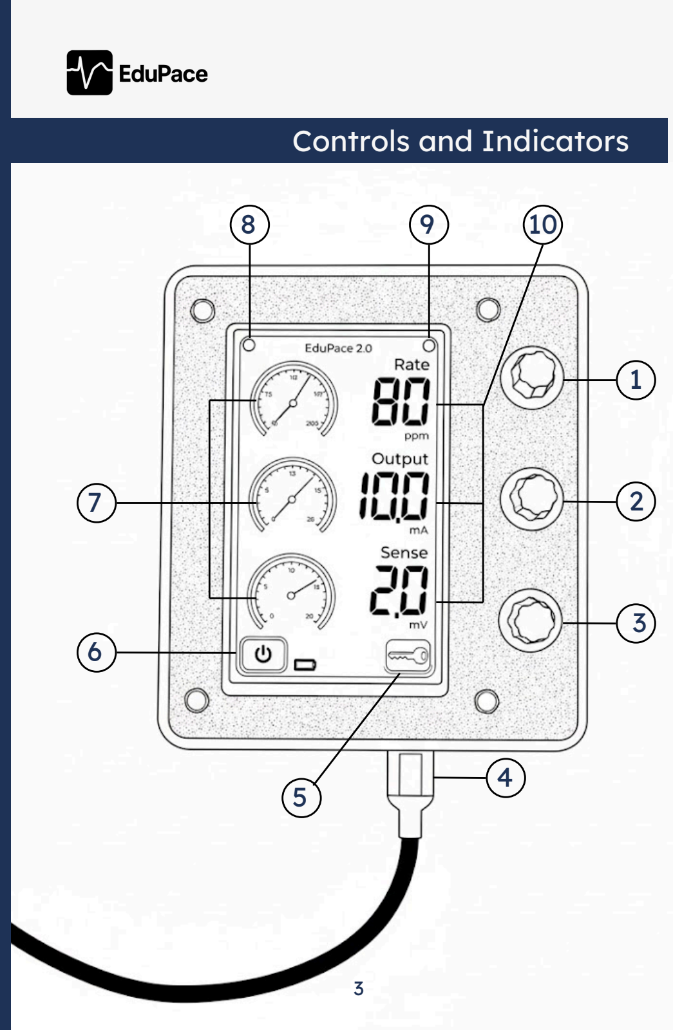
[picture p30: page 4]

1

2

3

4

6

5

7

## Controls and Indicators

### 1. RATE dial 2. OUTPUT dial 3. SENSE dial 4. USB-C input 5. Touchable Lock/Unlock button 6. Touchable On/Off button 7. Dashboard for RATE, OUTPUT, SENSE 8. Pacing status indicator LED 9. Sensing status indicator LED 10. Numeric indicators for RATE, OUTPUT, SENSE

## System Installation

# Software Installation

1.Open a web browser and go to https://github.com/joonhaim/edupace.git

2.Click on Releases on the right side of the page as shown below.

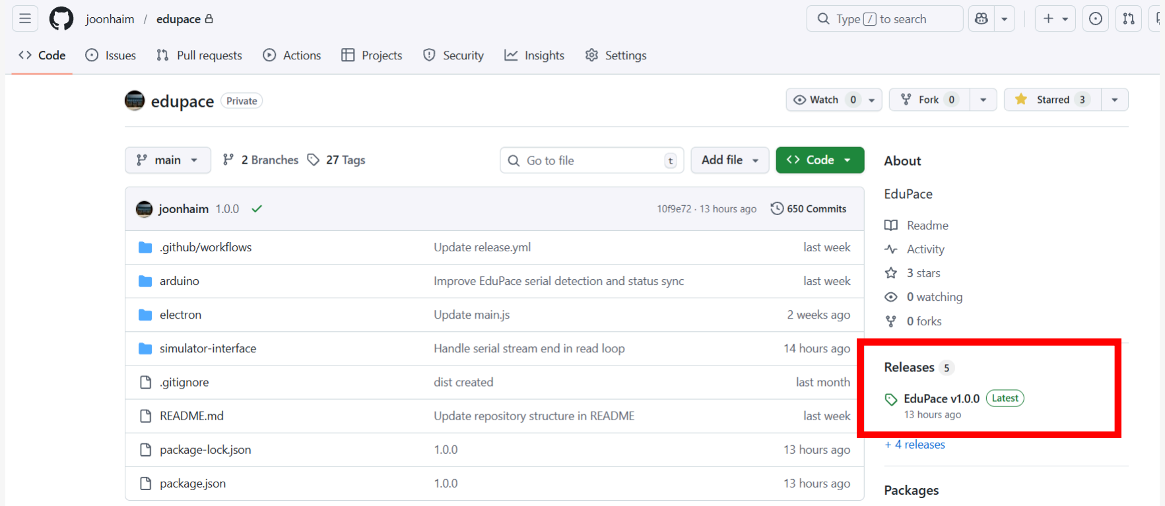
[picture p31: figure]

## System Installation

3.Download the appropriate installation file for your device: Windows: Click EduPace-1.0.0-win-x64.exe macOS: Click EduPace-1.0.0-mac-arm64.dmg

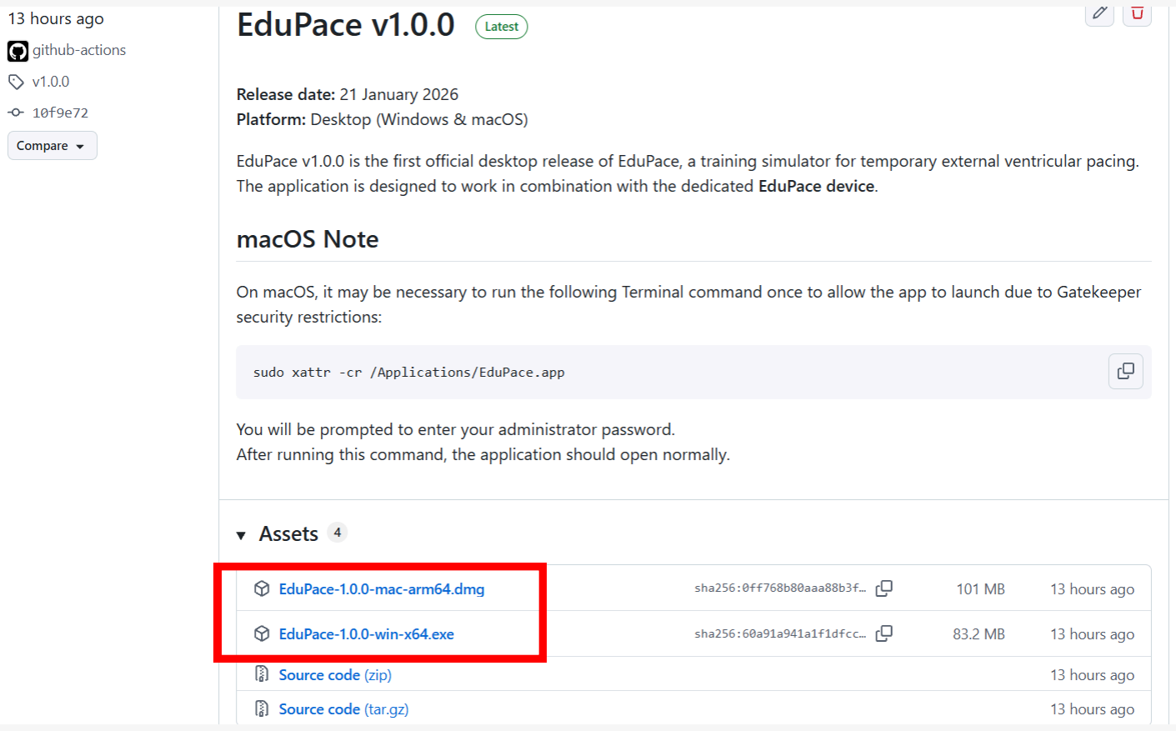
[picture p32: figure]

## System Installation

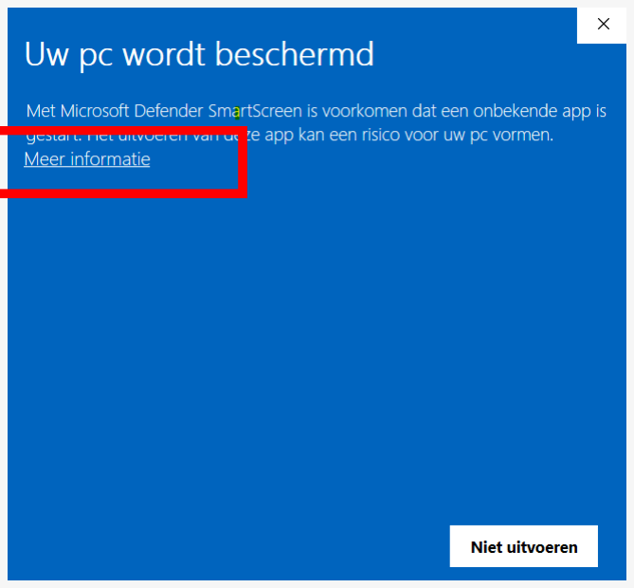
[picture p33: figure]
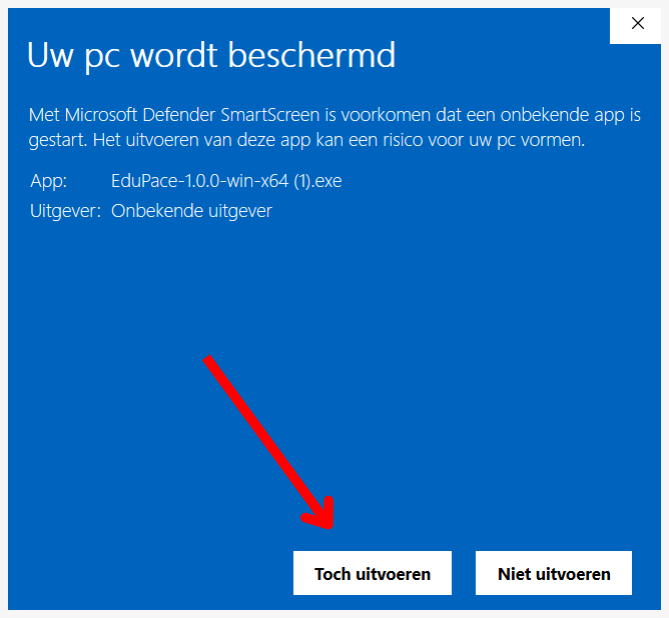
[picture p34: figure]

5.The installation wizard will appear. Click Next, then select Install to complete the installation process.

6.EduPace is now installed on your computer. You can now start using the software. Look for the following icon:

4.Open the downloaded EduPace file to begin installation. Windows users: If a security warning appears, click More info, then select Run anyway (“Toch uitvoeren”). This is safe.

## System Setup

# System Connector Setup

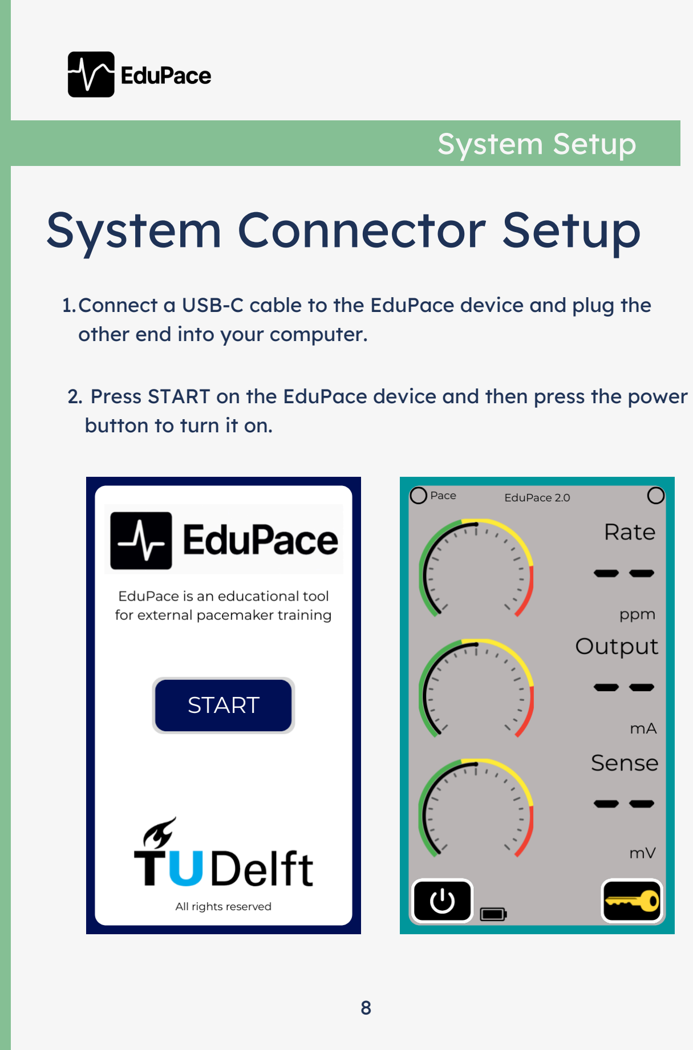
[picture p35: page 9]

1.Connect a USB-C cable to the EduPace device and plug the other end into your computer.

2. Press START on the EduPace device and then press the power button to turn it on.

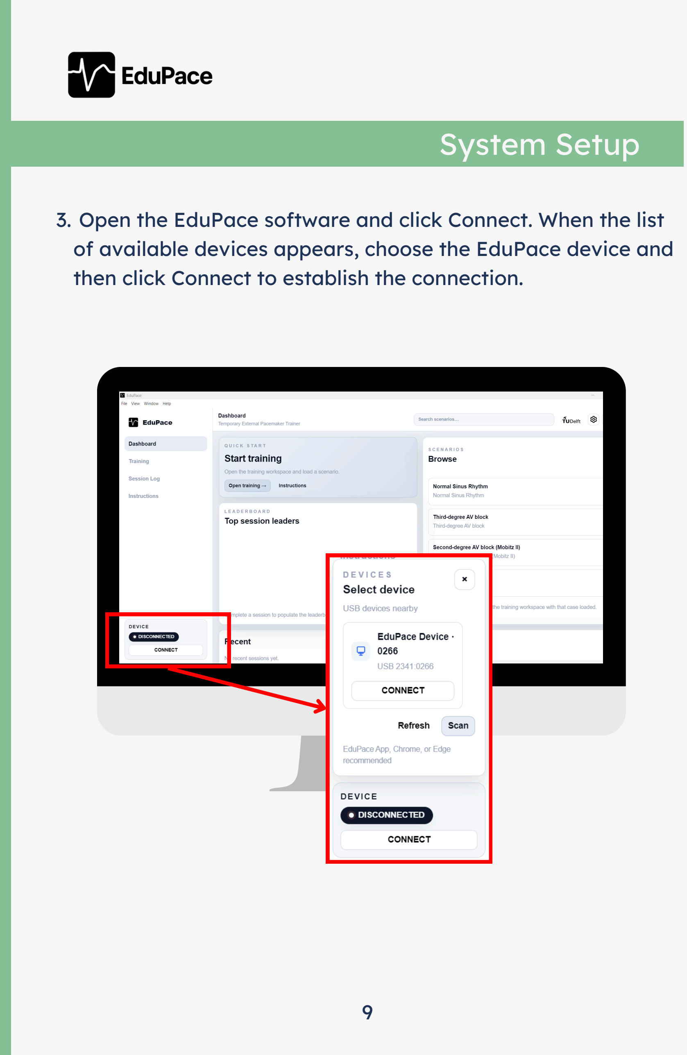
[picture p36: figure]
System Setup

3. Open the EduPace software and click Connect. When the list of available devices appears, choose the EduPace device and then click Connect to establish the connection.

4. Go to Training and select a scenario and then click "Start" to begin the session. The ECG trace will then appear on the screen.

## System Setup

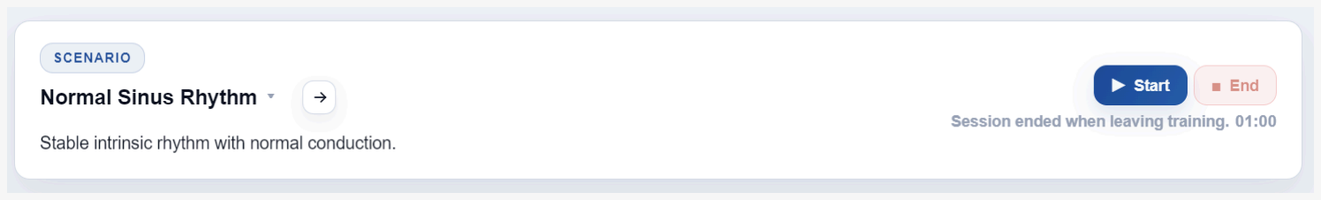
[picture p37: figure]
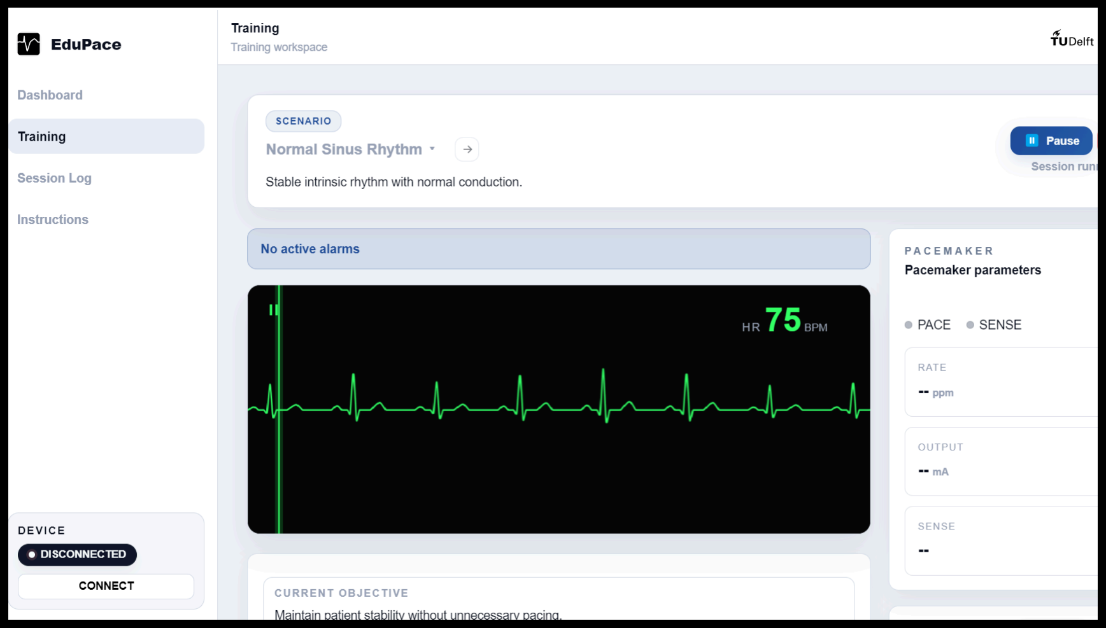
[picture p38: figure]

## Basic Operations

# To Turn On/Off

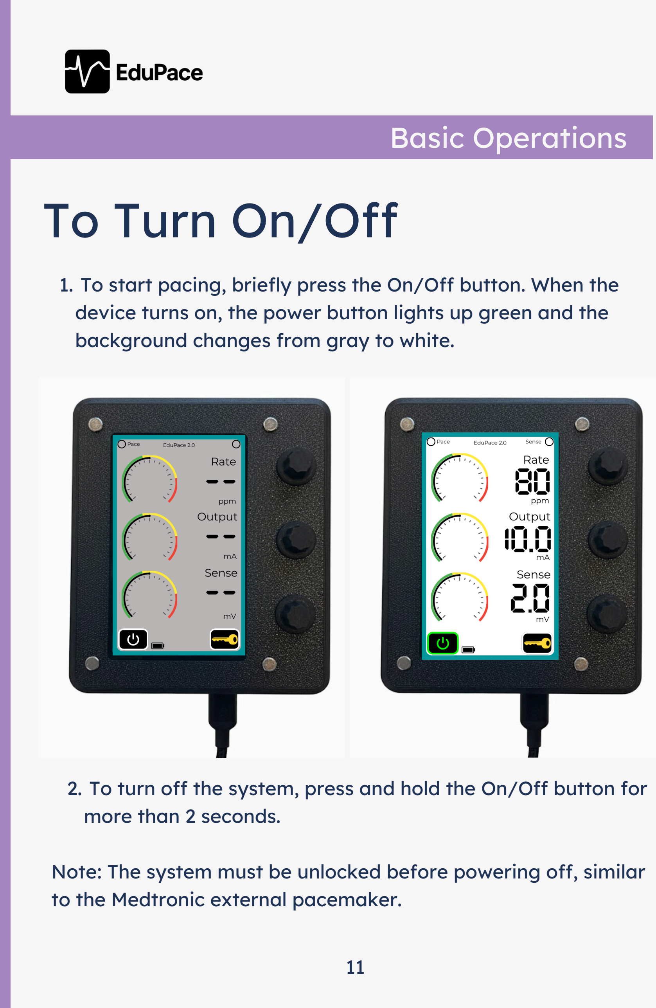
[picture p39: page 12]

1. To start pacing, briefly press the On/Off button. When the device turns on, the power button lights up green and the background changes from gray to white.
2. To turn off the system, press and hold the On/Off button for more than 2 seconds.

Note: The system must be unlocked before powering off, similar to the Medtronic external pacemaker.

## Basic Operations

# Lock/Unlock

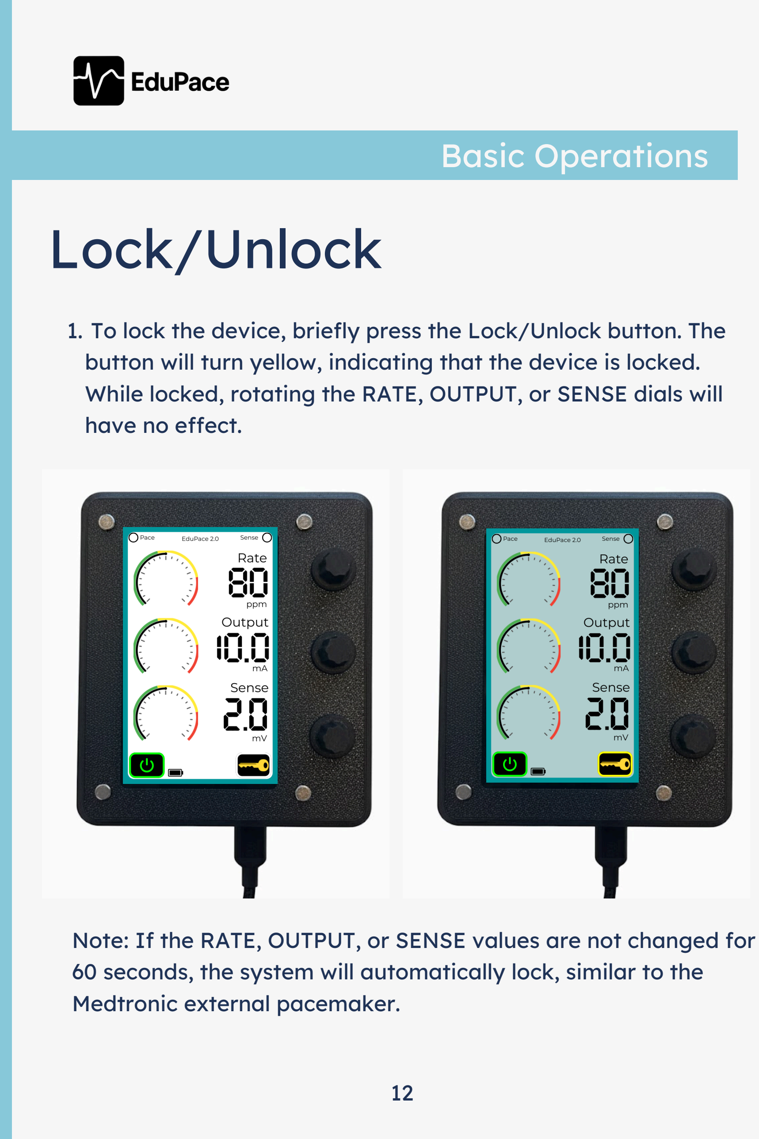
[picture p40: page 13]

1. To lock the device, briefly press the Lock/Unlock button. The button will turn yellow, indicating that the device is locked. While locked, rotating the RATE, OUTPUT, or SENSE dials will have no effect.

Note: If the RATE, OUTPUT, or SENSE values are not changed for 60 seconds, the system will automatically lock, similar to the Medtronic external pacemaker.

## Basic Operations

# Rate, Output, and

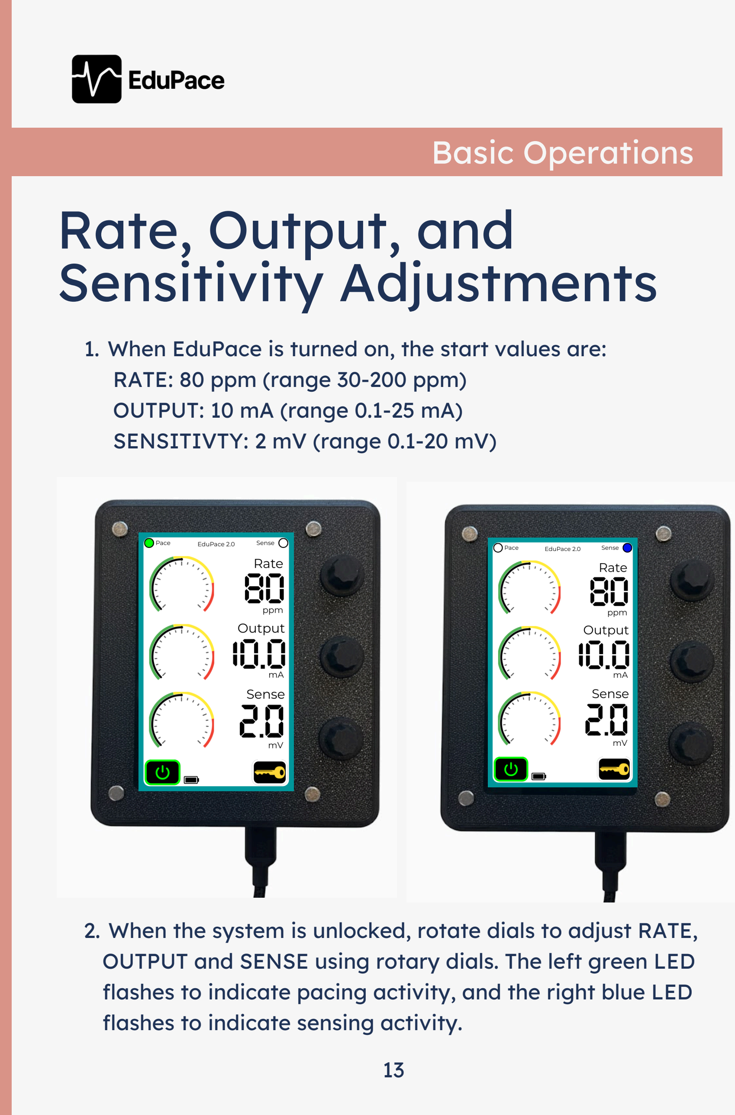
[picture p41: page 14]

1. When EduPace is turned on, the start values are: RATE: 80 ppm (range 30-200 ppm)
OUTPUT: 10 mA (range 0.1-25 mA) SENSITIVTY: 2 mV (range 0.1-20 mV)

# Sensitivity Adjustments

2. When the system is unlocked, rotate dials to adjust RATE, OUTPUT and SENSE using rotary dials. The left green LED flashes to indicate pacing activity, and the right blue LED flashes to indicate sensing activity.

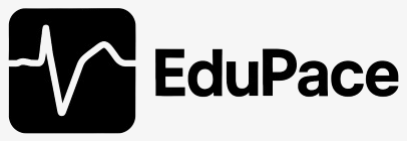
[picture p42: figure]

2025-2026

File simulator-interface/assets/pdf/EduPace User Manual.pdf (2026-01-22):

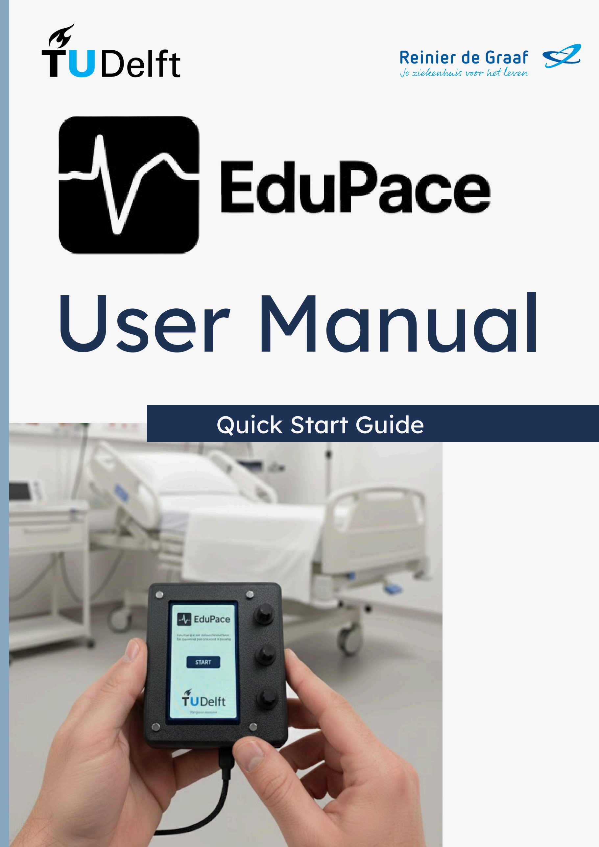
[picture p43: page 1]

# User Manual

## Quick Start Guide


All rights reserved 2025

1

# What is EduPace?

EduPace is an educational training tool designed for practicing the use of an external pacemaker. It has been developed by university students from TU Delft for educational purposes, specifically to support the training of nurses and clinicians.

## Before you begin

# Reference Device

The design and functionality of EduPace are based on the Medtronic 53401 External Pacemaker, which was used as a reference during development.

# Disclaimer

EduPace is not a medical device and is not intended for clinical use. It is an educational exercise tool only and must not be used for diagnosis, treatment, or patient care. Always use certified medical devices in clinical settings.

2

## Controls and Indicators

8 | 9 | 10

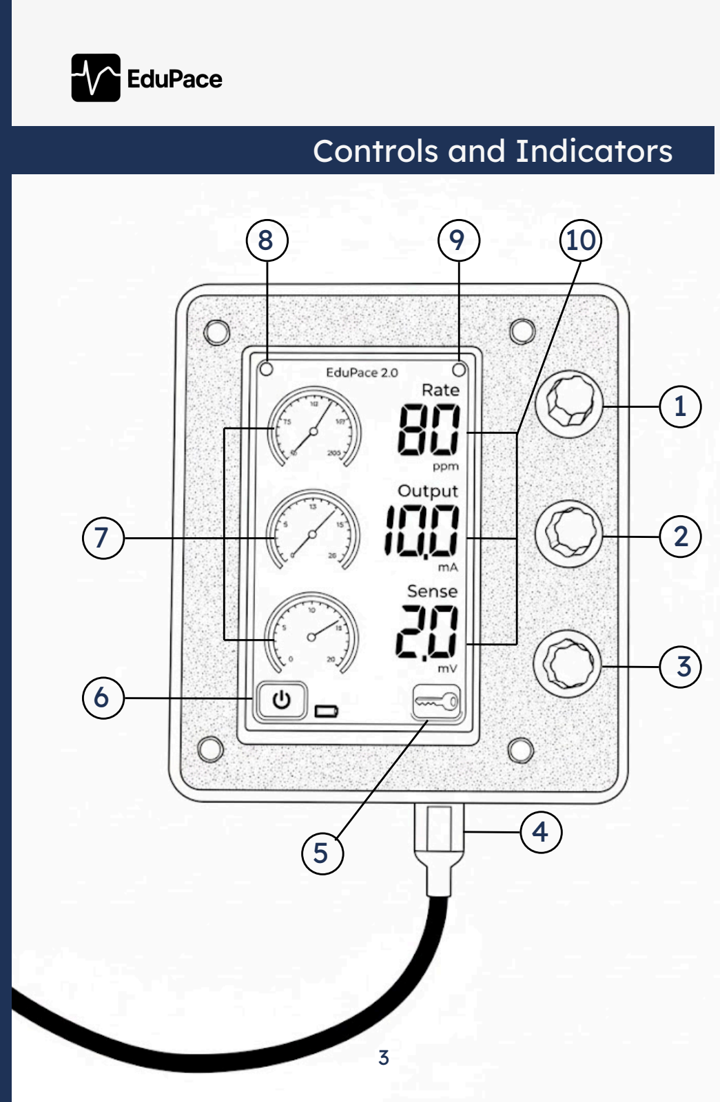
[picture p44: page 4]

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
## Controls and Indicators

### 1. RATE dial 2. OUTPUT dial 3. SENSE dial 4. USB-C input 5. Touchable Lock/Unlock button 6. Touchable On/Off button 7. Dashboard for RATE, OUTPUT, SENSE 8. Pacing status indicator LED 9. Sensing status indicator LED 10. Numeric indicators for RATE, OUTPUT, SENSE

4

## System Installation

# Software Installation

1.Open a web browser and go to https://github.com/joonhaim/edupace.git

2.Click on Releases on the right side of the page as shown below.


5

## System Installation

3.Download the appropriate installation file for your device: Windows: Click EduPace-1.0.0-win-x64.exe macOS: Click EduPace-1.0.0-mac-arm64.dmg


6

## System Installation


5.The installation wizard will appear. Click Next, then select Install to complete the installation process.

7

6.EduPace is now installed on your computer. You can now start using the software. Look for the following icon:

4.Open the downloaded EduPace file to begin installation. Windows users: If a security warning appears, click More info, then select Run anyway (“Toch uitvoeren”). This is safe.

## System Setup

# System Connector Setup

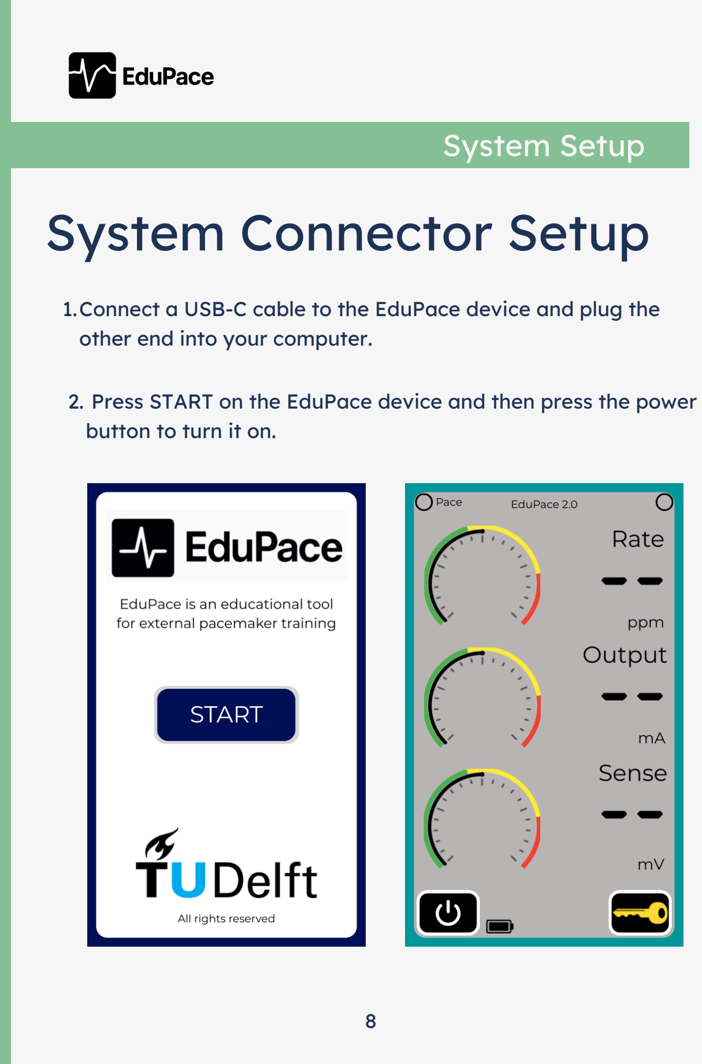
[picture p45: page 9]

1.Connect a USB-C cable to the EduPace device and plug the other end into your computer.

8

### 2. Press START on the EduPace device and then press the power

button to turn it on.

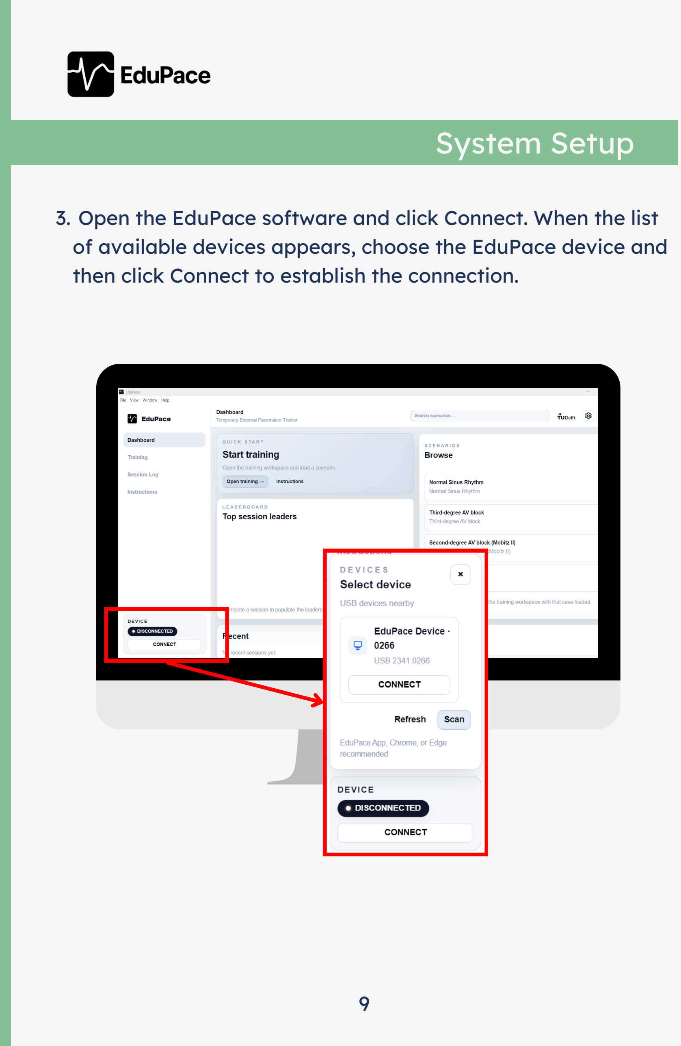
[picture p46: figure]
System Setup

### 3. Open the EduPace software and click Connect. When the list

of available devices appears, choose the EduPace device and then click Connect to establish the connection.

### 4. Go to Training and select a scenario and then click "Start" to

begin the session. The ECG trace will then appear on the screen.


10

## System Setup

## Basic Operations

# To Turn On/Off

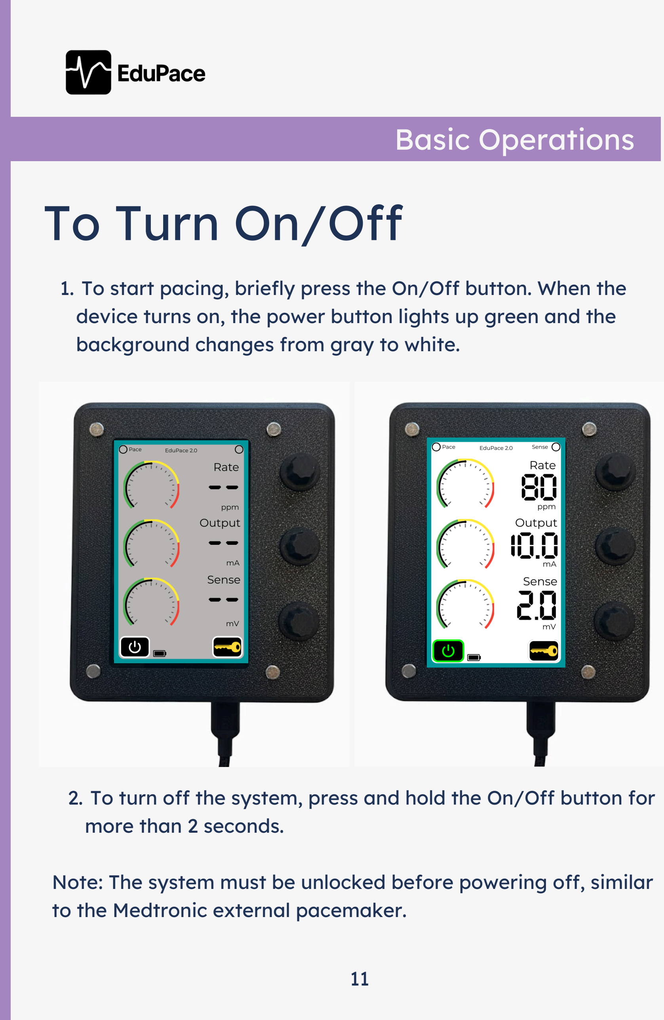
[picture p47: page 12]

### 1. To start pacing, briefly press the On/Off button. When the

device turns on, the power button lights up green and the background changes from gray to white.

### 2. To turn off the system, press and hold the On/Off button for

more than 2 seconds.

Note: The system must be unlocked before powering off, similar to the Medtronic external pacemaker.

11

## Basic Operations

# Lock/Unlock

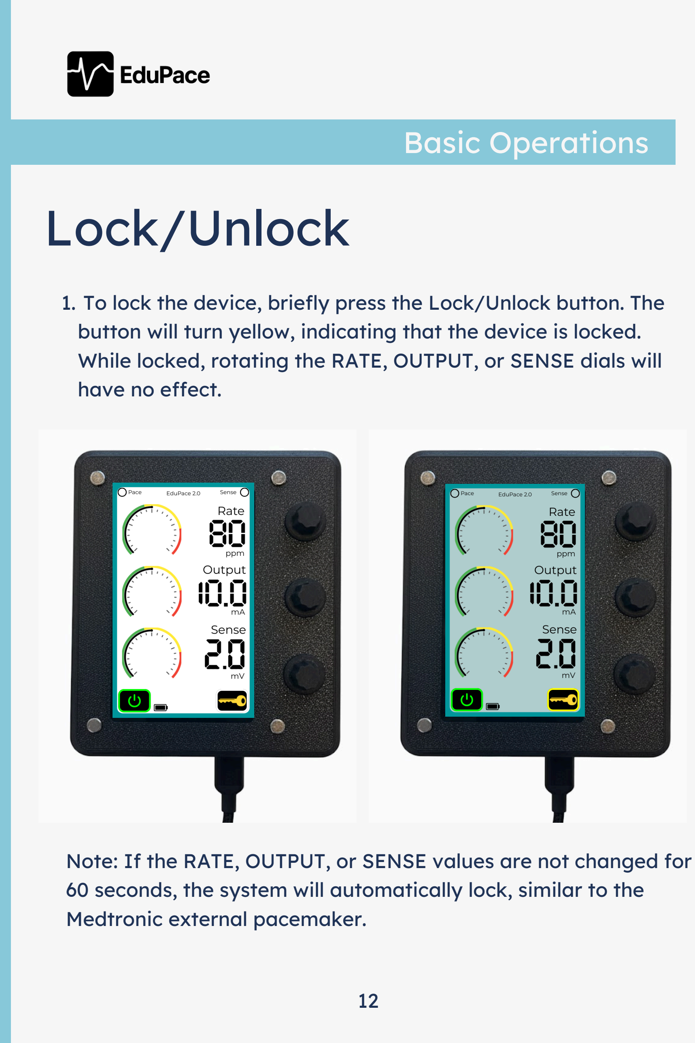
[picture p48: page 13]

### 1. To lock the device, briefly press the Lock/Unlock button. The

button will turn yellow, indicating that the device is locked. While locked, rotating the RATE, OUTPUT, or SENSE dials will have no effect.

Note: If the RATE, OUTPUT, or SENSE values are not changed for

### 60 seconds, the system will automatically lock, similar to the

Medtronic external pacemaker.

12

## Basic Operations

# Rate, Output, and

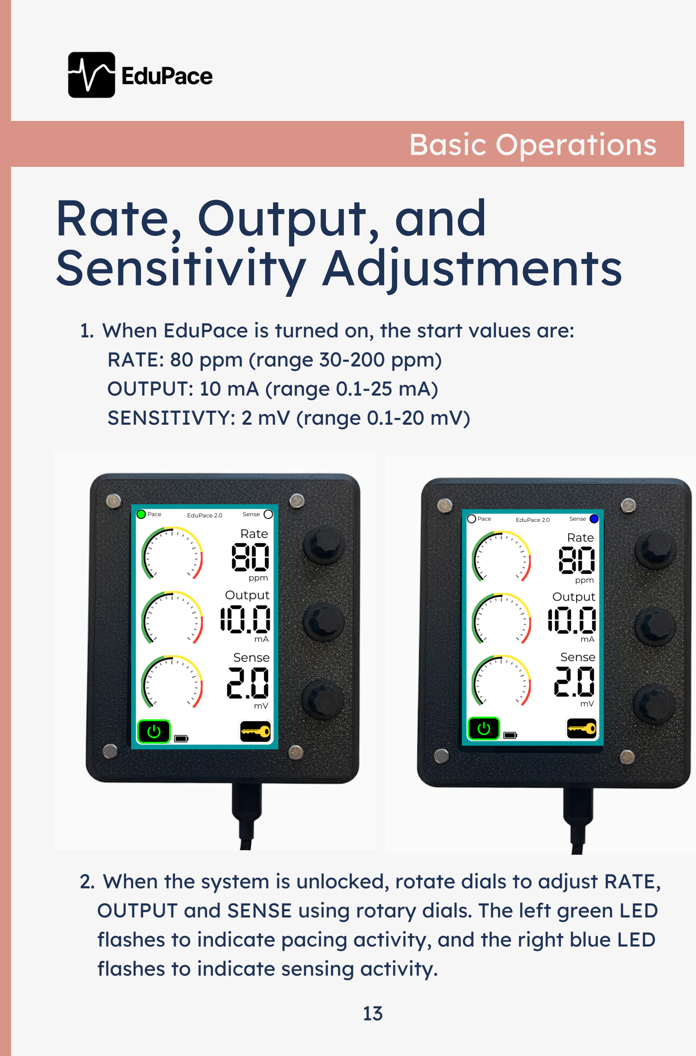
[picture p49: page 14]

### 1. When EduPace is turned on, the start values are:

RATE: 80 ppm (range 30-200 ppm)
OUTPUT: 10 mA (range 0.1-25 mA) SENSITIVTY: 2 mV (range 0.1-20 mV)

# Sensitivity Adjustments

2. When the system is unlocked, rotate dials to adjust RATE, OUTPUT and SENSE using rotary dials. The left green LED flashes to indicate pacing activity, and the right blue LED flashes to indicate sensing activity.

13


2025-2026

14

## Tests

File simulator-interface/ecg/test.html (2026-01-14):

Patient Scenario: —

Scenario

Intrinsic HR (bpm)

Value

-10 -1 +1 +10

Pacemaker Pacer: —

Rate (bpm)

Value

-10 -1 +1 +10

Output (mA)

Value

-1 -0.1 +0.1 +1

Sensitivity (mV)

Value

-1 -0.1 +0.1 +1

Asynchronous

Pacemaker: ON Monitor sweep (play/pause) Clear monitor

Top: ECG paper view (0–6 s) with red grid and blue sensitivity line.
Bottom: monitor view (black) uses a sweep to overwrite (no full reset) using the exact same trace.
Note: Regularity is fixed to Regular and Seed is removed.

samples: — t: —, y: — beats: —

ECG Paper Strip (static 0–6 s)

ECG Monitor (sweep overwrite of same trace)

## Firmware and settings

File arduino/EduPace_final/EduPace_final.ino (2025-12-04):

/*============================================================
  EduPace 2025
  Hardware: Arduino GIGA R1 + GIGA Display Shield
  Serial Baud Rate: 115200
  ------------------------------------------------------------
  COMMUNICATION FORMAT
  ------------------------------------------------------------
  ► Incoming Serial Commands:
    GREEN_ON   / GREEN_OFF
    BLUE_ON    / BLUE_OFF

  ► Outgoing Serial Messages:
    PACE=<value>, OUTPUT=<value>, SENSE=<value>
    POWER_ON
    POWER_OFF
  ------------------------------------------------------------
  USER INTERACTION
  ------------------------------------------------------------
  ► Power Button:
    – Hold > 2 seconds  → Toggle ON → OFF
    – Short press  → Toggle OFF → ON
    – ignored when locked

  ► Key Button:
    – Single press      → Lock / Unlock 

  ► Encoder Knobs:
    – Rotate to adjust PACE, OUTPUT, or SENSE
    – Rotation ignored when locked
  ------------------------------------------------------------
  Notes:
  – Display UI uses LVGL
  ============================================================ 
*/

#include "lvgl.h" //LVGL graphics library for buttons etc.
#include "Arduino_H7_Video.h"  //controls GIGA display
#include "Arduino_GigaDisplayTouch.h" //reads touch input
#include "lv_conf.h" 
#include <math.h> // needed for isnan()

LV_IMG_DECLARE(key);
LV_IMG_DECLARE(tu_logo_img)
LV_IMG_DECLARE(edupace_logo_img)
LV_IMG_DECLARE(edupace_logo_small_img)
LV_FONT_DECLARE(digital)

Arduino_H7_Video          Display(480, 800, GigaDisplayShield); 
Arduino_GigaDisplayTouch  TouchDetector;

//Splash screen
bool appStarted = false;

lv_obj_t * splash_scr;
lv_obj_t * main_scr;
lv_obj_t * start_btn;

//Lock button 
unsigned long lastChangeTime = 0; // time of last pace/output/sense change
const unsigned long autoLockInterval = 60000; // 60 seconds in milliseconds

bool key_pressed = false; 
bool autoLocked = false;

//Power button
bool power_pressed = false;
unsigned long powerBtnPressTime = 0;          // long press timestamp
const unsigned long powerHoldDuration = 2000; // 2 seconds hold

//Led States
bool greenState = false;  // current state of green LED
bool blueState  = false;  // current state of blue LED

//Encoder values (Default values: Pace 80, output 10, sensen 2.0)
float pace = 80;
float output = 10;
float sense = 2.0;

// For serial transmission of updated values
float lastPace = -1;
float lastOutput = -1;
float lastSense = -1;

//Indexes 
int paceIndex = 19;
int outputIndex = 19;
int senseIndex = 5;

//Steps for lookup tables 
const int paceSteps = 50;
const int outputSteps = 35;
const int senseSteps = 21;

lv_obj_t * cont;   //main container

// Pin definitions
#define inputA1 2
#define inputB1 3
#define inputA2 6
#define inputB2 7
#define inputA3 12
#define inputB3 13

// Rotary State
int AState1, ALastState1;
int AState2, ALastState2;
int AState3, ALastState3;

void setup() {
  Serial.begin(115200);
  lv_init();

  Display.begin();
  TouchDetector.begin();

  showSplashScreen();  
}

void loop() {
  if (appStarted) {
    updateEncoders();
    updateDisplayLabels();
    updateDial();

    sendUpdatedValues();
    handleSerialSignals();

    updateLeds();
    checkAutoLock();
  }
  lv_timer_handler();
  delay(5);
}

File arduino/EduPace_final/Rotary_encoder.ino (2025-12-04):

/*Rotary Encoders 

Encoder 1 (pace): 30 35 40 45 50 52 54 56 58 60 62 64 66 68 70 72 74 76 78 80 82 84 86 88 90 92 94 96 98 100 105 110 115 120 125 130 135 140 145 150 155 160 165 170 175 180 185 190 195 200  
Encoder 2 (output): 0.1 0.2 0.3 0.4 0.6 0.8 1 1.5 2 2.5 3 3.5 4 4.5 5 6 7 8 9 10 11 12 13 14 15 16 17 18 19 20 21 22 23 24 25
Encoder 3 (sense): 0.4 0.6 0.8 1 1.5 2 2.5 3 4 5 6 7 8 9 10 12 14 16 18 20 ASYNC

Clockwise rotation: (when B != A)
A:  _|‾‾|__|‾‾|__           A: 0-> 1  
B:    _|‾‾|__|‾‾|__         B: 0

Counter-clockwise rotation (when B == A)
A:    _|‾‾|__|‾‾|__         A: 0->1
B:  _|‾‾|__|‾‾|__           B: 1

*/

/*PIN Connections

GLOBAL
GND         -> GND (black)
+           -> 5V (red)

ENCODER 1
B DT (data)   -> digital pin (3) (blue)
A CLK (clock) -> digital pin (2) (yellow)

ENCODER 2
B DT (data)   -> digital pin (7) (green)
A CLK (clock) -> digital pin (6) (orange)

ENCODER 3
B DT (data)   -> digital pin (13) (gray)
A CLK (clock) -> digital pin (12) (white)*/

//Lookup Tables
const float paceTable[] = {
  30,35,40,45,50,52,54,56,58,60,62,64,66,68,70,72,
  74,76,78,80,82,84,86,88,90,92,94,96,98,100,105,110,
  115,120,125,130,135,140,145,150,155,160,165,170,175,180,
  185,190,195,200
};

const float outputTable[] = {
  0.1,0.2,0.3,0.4,0.6,0.8,1,1.5,2,2.5,3,3.5,4,4.5,5,
  6,7,8,9,10,11,12,13,14,15,16,17,18,19,20,21,22,23,24,25
};

const float senseTable[] = {
  0.4,0.6,0.8,1,1.5,2,2.5,3,4,5,6,7,8,9,10,12,14,16,18,20
};


void setupEncoders(){

  pinMode (inputA1, INPUT_PULLUP);
  pinMode (inputB1, INPUT_PULLUP);

  pinMode (inputA2, INPUT_PULLUP);
  pinMode (inputB2, INPUT_PULLUP);

  pinMode (inputA3, INPUT_PULLUP);
  pinMode (inputB3, INPUT_PULLUP);
  
  Serial.begin (115200);

  //Initialize previous states 
  ALastState1 = digitalRead(inputA1);
  ALastState2 = digitalRead(inputA2);
  ALastState3 = digitalRead(inputA3);
}

void updateEncoders(){

  if (!power_pressed){
    return;
  }

  //Encoder 1 - Pace
  AState1 = digitalRead(inputA1); //is pinA high or low now?
  if (AState1 != ALastState1){ //is there a change? low->high or high>low

    if (!key_pressed && power_pressed && !autoLocked){
      float oldPace = pace;
      if (digitalRead(inputB1) != AState1) {
        if (paceIndex < paceSteps -1){
          paceIndex++; //clockwise
        }
      }

      else{
        if (paceIndex > 0){
          paceIndex--; //counter-clockwise 
        }
      }

      pace = paceTable[paceIndex]; //update when the key is not pressed 
      if (pace != oldPace) lastChangeTime = millis(); // update timer on change
    }
  }
  ALastState1 = AState1;

  //Encoder 2 - Output
  AState2 = digitalRead(inputA2);
  if (AState2 != ALastState2) {

    if (!key_pressed && power_pressed && !autoLocked){
      float oldOutput = output;
      if (digitalRead(inputB2) != AState2){
        if (outputIndex < outputSteps - 1)
          outputIndex++;
      }

      else{
        if (outputIndex > 0)
          outputIndex--;
      }

      output = outputTable[outputIndex];
      if (output != oldOutput) lastChangeTime = millis(); // update timer on change
    }
  }
  ALastState2 = AState2;

  //Encoder 3 - Sense
  AState3 = digitalRead(inputA3);
  if (AState3 != ALastState3) {

    if(!key_pressed && power_pressed && !autoLocked){
      float oldSense = sense;
      if (digitalRead(inputB3) != AState3){
        if (senseIndex < senseSteps - 1)
          senseIndex++;
      }

      else {
        if (senseIndex > 0)
          senseIndex--;
      }

      if (senseIndex == senseSteps - 1 ){
        sense = NAN;
      }
      else {
        sense = senseTable[senseIndex];
        lastChangeTime = millis();
      }
    }
  }
  ALastState3 = AState3;
}

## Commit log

2025-11-11 Refactor README for improved text flow
    Removed unnecessary line break for better readability.
2025-11-17 Update README to simplify project description
    Removed mention of patient risk and simplified project description.
2025-11-20 Added sample heart signal
2025-11-20 Added documentation
    [EduPace Knob Presets.xlsx]
2025-11-20 added logic for uc-01 and redesigned device connection
2025-11-20 Refine device connection styling
2025-11-25 Implement sweeping ECG trace
2025-11-25 Brighten ECG trace
2025-11-25 Add power and lock controls to virtual pacemaker
2025-11-25 Require long press to power off virtual controller
2025-11-25 Color-code pace and sense LED flashes
2025-11-25 Add LED flash handling for pacing and sensing
2025-11-25 Gate pace and sense LEDs on power state
2025-11-26 update led logic
2025-11-28 Style power-button hint as dismissible toast
2025-11-28 Fix LED colors to remain constant
2025-11-29 Revamp ECG overlays and logs editing flow
2025-11-29 Refine calibration overlay and logs selection
2025-11-29 Improve calibration toggle and log detail interactions
2025-12-04 Deleted old arduino code
2025-12-09 Add serial device picker for serial connections
2025-12-09 removed docs folder
    [EduPace Knob Presets.xlsx]
2025-12-11 Filter device list to connected USB serial ports
2025-12-11 Add friendly EduPace label for Web Serial devices
2025-12-15 Update ECG simulation - more organised version.ipynb
    Pacing of 3rd degree heart block - work in progress but committing in case I mess stuff up later
2025-12-18 Add shared sidebar navigation with persistent device connection
2025-12-18 Redesign dashboard tiles and restore device copy
2026-01-10 Fix ECG frame size
2026-01-10 Fix serial power parsing and parameter display
2026-01-14 Update lock button icons
2026-01-14 Fix ECG trace reaching right edge
2026-01-14 Trigger pace LED on ventricular pacing beats
2026-01-16 Show all serial ports in device list
2026-01-19 Improve device labeling and list scrolling
2026-01-19 Refine serial device popover styling
2026-01-21 Improve device connection tile layout
2026-01-21 Add EduPace device identifiers
2026-01-21 Uppercase disconnect button label
2026-01-21 Make end session button red across themes
2026-01-25 added cad files
    [Assembly EduPace.SLDASM, Backside EduPace.SLDPRT, Enclosure EduPace.SLDPRT]
2026-09-02 Refine serial integration, UI, tests, and deps
    Enforce local Web Serial origin checks, restrict to known EduPace USB vendors, and implement a serial-port selector in electron main; ensure IPC handlers are registered only once. Bump Electron to v43, add serve/test scripts. Add arduinoProtocol.mjs and unit tests; refactor arduinoSerialAdapter to use the protocol parser, harden connect/read/disconnect logic, and better handle async mode and encoder/decoder streaming. Fix ECG canvas sizing by using clientWidth/clientHeight and remove inline bitmap sizing; add CSS and UI tweaks for native controls and layout. Add tests for serial adapter and ECG layout.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
2026-09-02 Improve ECG trace redraws and guide UI
    This change adds timeline-slice geometry to prevent redraw seams during ECG trace refreshes, joins adjacent slices with a small overlap, and updates calibration visibility state. It also introduces a sensitivity-guide toggle in the ECG overlay, wiring it to settings and styling the active state.
2026-09-03 Fix mobile responsive layout and build cleanup
    This commit removes development-only files from the generated static site and updates the mobile layout rules to avoid breaking ECG fullscreen and the phone-training flow. It also adds assertions covering the responsive CSS and mobile navigation behavior.
2026-10-09 Enable safe USB serial access
    This commit adds a dedicated Electron serial permission flow, replacing the old vendor-ID filtering with a user-driven USB port picker that works for Arduino-style devices and avoids unsafe automatic assumptions. It updates the simulator UI to reflect wired USB serial behavior, improves reconnection/error handling, and keeps connection states robust during disconnects and retries. It also adds automated tests covering serial access, reconnect logic, and Electron port selection.
